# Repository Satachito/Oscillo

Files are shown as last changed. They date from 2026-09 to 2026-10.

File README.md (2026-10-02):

# Oscillo

Oscilloscope projects: one instrument — oscilloscope, spectrum analyser, logic
analyser and meter — on a Raspberry Pi Pico 2 (PiLyzer) or an Arduino R4
(ArLyzer), and the applications that drive both.

| Project | Hardware | Applications |
| --- | --- | --- |
| [Pico2](Pico2/) | Raspberry Pi Pico 2, bare or behind a front end — the [PiLyzer AFE](Pico2/hardware/pilyzer-afe/), a one-op-amp [mini AFE](Pico2/hardware/mini-afe/), or a picoLABO [PL2407AFE](Pico2/hardware/pl2407afe/) | [macOS](Pico2/README.md) · [WebUSB](Pico2/Web/) |
| [ArLyzer](ArLyzer/) | Arduino Nano R4, UNO R4 Minima or UNO R4 WiFi — the same protocol as the Pico 2, up to eight analogue inputs and logic on D2–D9; the UNO R4 WiFi also over Wi-Fi | the same [macOS](Pico2/README.md) · [Web](Pico2/Web/) applications |
| [PCBScope](PCBScope/) | PCBScope / DPScope SE | Native macOS HID application restored from the original project |

**[Open PiLyzer Web](https://satachito.github.io/Oscillo/)** ·
**[Download macOS releases](https://github.com/Satachito/Oscillo/releases)** ·
**[Watch the introduction](https://youtu.be/e5NLnyxRusI)** (6 min, Japanese with English subtitles)

The build log, in English with Japanese subtitles: [PiLyzer #1](https://youtu.be/wvEdqJw_1fM) ·
[PiLyzer #2](https://youtu.be/XWv_rssCQdA) · [ArLyzer on three Arduino R4 boards](https://youtu.be/QQOrhekh34A)

PiLyzer's firmware, KiCad schematics, documentation and native app now live
under `Pico2/`; ArLyzer's sketch and the UNO R4 WiFi's Wi-Fi bridge under
`ArLyzer/`. The Git repository remains at this level. Each native app is
an independent Swift package; run its build commands from its own directory.

```sh
(cd Pico2 && ./Scripts/make-app.sh)
(cd PCBScope && ./Scripts/make-app.sh)
```

PiLyzer Web talks directly to the instrument in Chrome or Edge on a desktop
computer — macOS, Windows and Linux alike, with nothing to install on any of
them: WebUSB for a Pico 2 (firmware 1.6 and later), Web Serial for an ArLyzer.
A Pico 2 W or an UNO R4 WiFi serves it itself over Wi-Fi, at
`http://pilyzer.local` or `http://arlyzer.local`, so a phone or a tablet needs
no USB at all. Demo mode also works without an instrument.
Captured samples remain in the browser; CSV export saves them locally.
From 3.3.6, the copy on GitHub Pages counts page views, and which way an
instrument was connected (USB, serial or the demo), with Google Analytics. The
copy a board serves, and one run locally, load nothing of the kind, and no
samples, readings or device details are sent.

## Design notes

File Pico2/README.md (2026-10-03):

# PiLyzer

A three-channel oscilloscope, spectrum analyser and eight-channel logic analyser
built on a Raspberry Pi Pico 2, with a native macOS application to drive it.

The RP2350 appears as a vendor-specific USB device, so the application claims it
directly through IOKit: no driver, no kext, no permission dialog, no Python.

The macOS application and the browser application in [Web/](Web/) are the same
instrument seen through two windows, and are drawn to match: one palette, one
layout, one set of readings. The colours come from the custom properties at the
top of `Web/style.css`, light and dark alike, and both applications follow the
system appearance.

Only the paper around the instrument changes with it. The screen does not: an
oscilloscope's face is dark on a bench under any lighting, the trace colours are
chosen against that dark, and a screen that inverted with the system would give
every reading a different colour from the one you learned.

## Downloads and Web app

[Download PiLyzer for macOS](https://github.com/Satachito/Oscillo/releases/latest)
(Apple Silicon + Intel, macOS 13+) or
[open PiLyzer Web](https://satachito.github.io/Oscillo/).
The WebUSB app lives in [Web/](Web/) and needs Chrome or Edge for USB — on a
computer, or on Android through USB On-The-Go.
The same release carries the firmware as UF2 files — for a Pico 2, a Pico 2 W
and a Pico 2 on the PL2407AFE; see
[firmware/pilyzer](firmware/pilyzer/README.md#without-building).
From 3.3.6, PiLyzer Web on GitHub Pages counts page views and which way an
instrument was connected; the copy a Pico 2 W serves does not
([Web/README.md](Web/README.md)).

The macOS download is ad-hoc signed, not Apple-notarized. Unzip it and move
PiLyzer.app to Applications. macOS may require approving its first launch in
System Settings → Privacy & Security → Open Anyway.

The same firmware and both applications serve a bare Pico 2, [the rev A front
end](hardware/pilyzer-afe) — three channels, two switched ranges, and a
one-range build for a bench that wants no switch — and a picoLABO
[PL2407AFE](hardware/pl2407afe). None of them needs its own release of either
application: the board describes its own front end from firmware 1.7.

Both applications also drive an Arduino Nano R4, UNO R4 Minima or UNO R4 WiFi
running [ArLyzer](../ArLyzer/), a sketch that speaks this same protocol: up to
eight analogue inputs at 0–5 V and a logic analyser on D2–D9, slower than the
Pico 2 but with more inputs. It connects over USB serial — **Serial** in PiLyzer
Web, the instrument list in the macOS application — and the UNO R4 WiFi also
serves PiLyzer Web itself at `http://arlyzer.local`.

All commands below run from the `Pico2` directory.

## What it is

| | |
| --- | --- |
| Analogue | 3 channels, 12 bits, 40 kHz; 495 / 247 / 165 kSa/s per channel with 1 / 2 / 3 enabled |
| Vertical | ±25 V and ±5 V, switched from the application |
| Record | up to 16 384 points a channel, with pre-trigger |
| Spectrum | windowed FFT of every enabled channel, with averaging, THD, THD+N, SNR, SINAD and ENOB for each |
| Logic | 8 channels, up to 150 MSa/s, 65 536 points, UART / SPI / I²C decoding |
| Trigger | edge, with hysteresis, on any analogue channel or any logic input |

There is a built-in signal generator, so the whole application works with
nothing plugged in:

```bash
swift run PiLyzer --demo
```

`--mode scope|spectrum|logic|meter` opens on one of the four screens, and
`--autostart` connects to the remembered instrument and starts sweeping.

Three flags answer without opening a window, which is what to reach for when an
instrument does not appear in the list:

```bash
swift run PiLyzer --list       # what is on the USB bus, and why it is not an instrument
swift run PiLyzer --selftest   # walk the whole command set against a real board
swift run PiLyzer --timing     # measure the time axis against the calibration output
swift run PiLyzer --testout 1000   # drive that output, or "off"
swift run PiLyzer --signals 440    # sine and the three noises on the board's own pins, or "off"
swift run PiLyzer --bootsel    # restart it in its bootloader to load new firmware
```

## Requirements

* macOS 13 or later
* Xcode 16 or later (Swift 6 toolchain) to build the application
* A Raspberry Pi Pico 2 running the firmware in `firmware/pilyzer`
* Optionally the analogue front end in `hardware/pilyzer-afe`, which is what
  makes anything outside 0–3.3 V safe to measure

## Building and running

```bash
./Scripts/make-app.sh
```

Set `UNIVERSAL=1` to build for both Apple Silicon and Intel. The script
puts a double-clickable, ad-hoc signed `build/PiLyzer.app` together. To run from
the package instead, `swift run PiLyzer`. Tests:

```bash
swift test
```

The whole acquisition path is exercised against the built-in generator, so the
test suite needs no hardware.

The firmware has its own build; see [firmware/pilyzer/README.md](firmware/pilyzer/README.md).

## Using it

1. Pick the instrument (or **Demo signal**) in the toolbar and press
   **Connect** (⌘K). The list follows the hardware as it is plugged and
   unplugged. The application checks the firmware's identity, so nothing else
   on the bus can be mistaken for an instrument.
2. Press **Run** (⌘R) for continuous sweeps, or **Single** (⇧⌘S) for one.
3. **Export** (⌘E) writes what is on screen to CSV — samples, spectrum, logic
   transitions or decoded protocol, whichever screen is showing.

| Screen | |
| --- | --- |
| **Scope** | voltage against time, or X/Y; Vpp, mean, RMS, AC RMS, frequency, duty, rise time |
| **Spectrum** | every enabled channel on one axis, with peak markers and the distortion figures for each |
| **Logic** | eight traces, per-channel rate and duty, protocol decoding |
| **Meter / logger** | all inputs as numbers, and a log at 50 ms to 5 minutes a point — each point the lowest, mean and highest reading of its interval |

### The instrument tells the application what it can do

Nothing about the hardware is compiled into the application. On connecting it
asks the instrument for its capabilities — how many channels, how fast, how
deep, which ranges — and builds the sweep speeds, record lengths and range
menus from the answer. When a sweep is set up, the instrument replies with the
sample interval it will *actually* use, and that is what the time axis is
labelled with.

This is the reason the time axis can be trusted: it is a hardware register
divided down, not a number the application hoped for.

It is also why the same applications drive [ArLyzer](../ArLyzer/) on an
Arduino R4 with no code of its own beyond naming the pins: the board answers
the same questions with its own figures.

### Fast sweeps show fewer points, not invented ones

The converter runs at 165 kSa/s a channel with all three on. A sweep faster than the record length
can be filled at that rate keeps the converter flat out and **shortens the
record** instead of interpolating: at 50 µs/div you get 125 real samples across
the screen rather than 2 000 imaginary ones. The panel always shows the rate and
the point count it settled on.

The other direction is handled by averaging rather than skipping. Every sample
on a slow sweep is the mean of all the conversions underneath it, which is both
the anti-alias filter and where the extra bits below the converter's twelve come
from.

### Triggering a noisy or stepped waveform

**Trigger LPF** in the Scope panel filters only the signal used to find the
trigger. The displayed/exported waveform keeps its original steps and noise.
It defaults to Off. An on/off switch retains the last cutoff, and a logarithmic
slider covers 100 Hz to 100 kHz. The **1 kHz** shortcut enables that cutoff.
For a roughly 194 Hz waveform, 1 kHz is a starting point;
compare Off, 500 Hz, 1 kHz and 2 kHz against the actual signal. Keep the level
near the middle of the waveform, and use Normal mode to distinguish a real
trigger from an automatic sweep.

This setting requires firmware 1.2 or later. The trigger marker follows the
filtered crossing, so the raw trace can cross the level earlier. The filter
uses the actual sample interval, and is reset and allowed to settle at each arm.

### Calibration

Every reading is a straight line from a converter code to a voltage, and the
resistors that set it are ordinary 1% parts. Two points fix them:

1. **Zero.** Ground all inputs, then **Calibrate Zero** (⌘-menu, or the button
   on the channel). Whatever is read becomes zero for the range that channel is
   on.
2. **Gain.** Apply a known voltage and tell the application what it is.

Calibration is stored per channel *and per range*, because the two ranges go
through different amplifier gains.

The front end's frequency compensation is a physical adjustment, not a software
one: the firmware puts a square wave on GPIO22 for it, and
[the front end's documentation](hardware/pilyzer-afe/README.md) explains what to
turn.

## How it is put together

| Target | |
| --- | --- |
| `Sources/CPiLyzerUSB` | IOKit's USB interfaces, wrapped so Swift sees a handle |
| `Sources/PiLyzerCore` | protocol, transport, instrument, engine, FFT, decoders |
| `Sources/PiLyzerApp` | SwiftUI front panel and the four screens |
| `firmware/pilyzer` | RP2350 firmware |
| `hardware/pilyzer-afe` | analogue front end: KiCad schematic, footprints, values, BOM |
| `docs/protocol.md` | the contract between the firmware and the application |

`PiLyzerCore` has no interface dependencies. The real instrument and the demo
generator both implement `Instrument`, so every path from the front panel down
to the samples is covered by the tests.

Device traffic runs on one background queue, and no acquisition ever blocks the
interface.

Run one program against an instrument at a time. The application asks for
exclusive access and refuses to take it away from another process, because two
clients on one bulk endpoint would read each other's answers.

## Limits worth knowing before you trust a reading

* **Bandwidth is 40 kHz**, set by a two-pole Sallen-Key on each channel rather
  than by the converter. The corner is sized for the three-channel case, where
  Nyquist is 82 kHz, so one- and two-channel modes are limited by the filter
  and not by the sample rate. Two poles reduce what folds back; they do not
  abolish it. This is an audio and low-frequency instrument.
* **The fastest sweep is 20 µs/div with one channel, 50 µs/div with two or
  three**, where a division holds five samples. There is no equivalent-time
  sampling yet.
* **Nothing is isolated.** Everything shares the Mac's USB ground. Not for mains
  primary circuits, and not for anything floating at a dangerous potential.
* **The logic inputs are 3.3 V only.** There is no buffer and no level shifter.
* **The analogue and logic sides trigger independently**, so their records
  cannot be lined up against each other.
* A channel that reaches the ends of the converter has its legend label shown
  inverted: the trace is a flattened copy of the real signal and no
  calibration recovers it.

## Where this came from

This started as a rewrite of a macOS application for the DPScope SE, a PIC-based
USB HID instrument. When the hardware became a Pico 2 the old command set came
along with it for a while, and it fitted badly: registers of a microcontroller
that was no longer there, an eight-bit record, 211 samples, and an equivalent
time mode that existed only because the PIC could not sample faster than 30 µs.

None of it survives. The protocol, the firmware, the front end and the
application were designed again around what an RP2350 is actually good at:
hardware-paced conversion into DMA, a processor fast enough to find triggers in
the data, PIO fast enough to watch a pin at 150 MHz, and a USB link fast enough
that records do not have to be small.

## License

MIT. See [LICENSE](LICENSE).

Firmware 1.5 adds CH3 on GPIO28; the test output is GPIO22 (TP6).
Firmware 1.6 adds the WinUSB and WebUSB descriptors that let the browser
application open the instrument on Windows without a hand-installed driver, and
firmware 1.8 is the first in which Windows actually binds to them.
Logic is on GPIO6–13, the range controls are GPIO2/3/4 (firmware 1.13; before
that GPIO8–15 and GPIO4/5/6) and the signal generator has GPIO16–19 — the same four on every board, wherever it is plugged
in. The application uses
the channel count reported by the device, so older two-channel firmware remains
usable. Channel Enabled checkboxes control acquisition as well as display:
1 / 2 / 3 enabled channels allow up to 495 / 247 / 165 kSa/s per channel.
Slower timebases still use averaging/decimation; the actual rate and the current
channel-count limit appear in the Horizontal section.

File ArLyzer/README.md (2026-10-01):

# ArLyzer

PiLyzer's oscilloscope, spectrum analyser, logic analyser and meter on an
Arduino Nano R4, UNO R4 Minima or UNO R4 WiFi. The sketch speaks the same wire
protocol as the Pico 2 ([`Pico2/docs/protocol.md`](../Pico2/docs/protocol.md)),
so [PiLyzer Web](https://satachito.github.io/Oscillo/) and the macOS
application drive it unchanged: the board says what it can do, and the
applications draw from that.

| | Nano R4 | UNO R4 Minima | UNO R4 WiFi |
| --- | --- | --- | --- |
| Analogue | 8 ch, A0–A7 | 8 ch, A0–A5, D4, D5 | 7 ch, A0–A5, D10 |
| Fastest, per channel | 88 kSa/s with 1 input, 47 with 8 | the same | 88 kSa/s with 1 input, 50 with 7 |
| Record | 1,024 points a channel | the same | the same |
| Logic | D2–D9, up to 167 kSa/s, 16,384 points | the same | the same, 14,336 points |
| Connection | USB serial | USB serial | USB serial, and Wi-Fi with [the bridge](bridge/) |

The inputs are 0–5 V: the converter measures against the board's own 5 V
rail, which the firmware reads against the chip's internal reference, so the
readings hold when the USB supply is not quite 5 V. The logic inputs are 5 V
logic — a 3.3 V signal may not read high, so put a level shifter in front of
3.3 V circuits.

## Load it

Open [`arlyzer/`](arlyzer/) in the Arduino IDE with the Arduino UNO R4 Boards
package installed, pick the board and upload. Or with arduino-cli:

```sh
arduino-cli compile --fqbn arduino:renesas_uno:nanor4 arlyzer        # or :minima, :unor4wifi
arduino-cli upload  --fqbn arduino:renesas_uno:nanor4 -p <port> arlyzer
```

The [release](https://github.com/Satachito/Oscillo/releases/latest) carries a
build for each board — `ArLyzer-NanoR4.bin`, `ArLyzer-Minima.bin` and
`ArLyzer-R4WiFi.bin` — to load without building:

```sh
arduino-cli upload --fqbn arduino:renesas_uno:nanor4 -p <port> --input-file ArLyzer-NanoR4.bin   # :minima, :unor4wifi
```

## Use it

In PiLyzer Web (Chrome or Edge), press **Serial** and pick the board's port;
in the macOS application, pick it from the instrument list. Plug the USB in
before any signal: a signal on an unpowered board can power it through the
input pin and stop its USB from starting.

The UNO R4 WiFi can also serve PiLyzer Web itself, at `http://arlyzer.local`,
once its ESP32-S3 runs ArLyzer's bridge — see [`bridge/`](bridge/). The
network is then set from the application's Wi-Fi section, over USB.

## In this directory

| | |
| --- | --- |
| [`arlyzer/`](arlyzer/) | the sketch |
| [`bridge/`](bridge/) | the UNO R4 WiFi's ESP32-S3 firmware: Wi-Fi, `arlyzer.local` and the browser application |
| [`host/`](host/) | a simulated ArLyzer behind a pseudo-terminal, to drive the applications without a board |
| [`tests/`](tests/) | host tests for the record, the logic analyser and the network hand-over |
| [`tools/probe.py`](tools/probe.py) | asks a board who it is and reads its inputs, from the command line |

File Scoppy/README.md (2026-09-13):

# PiLyzer for PL2407AFE

購入したpicoLABO **PL2407AFE + Raspberry Pi Pico 2** 用のPiLyzer構成です。
ScoppyのAndroidアプリやファームウェアのコピーではありません。基板のAFEを利用し、PiLyzerのmacOS／Webアプリで測定します。

## 構成

- `firmware/board_config.h`: PL2407AFE専用GPIO・2ch・3レンジ換算値（board ID 3）。
- `firmware/build.sh`: 共通PiLyzerファームウェアをこの基板用にビルド。
- `Web/`: `../Pico2/Web`へのリンク。同じWebUSBアプリを使用。
- macOS: `../Pico2`のアプリを使用。入力レンジ記述子に対応した最新版が必要です。`cd ../Pico2 && ./Scripts/make-app.sh`でビルド。

アプリは接続したファームウェアから2ch・3レンジを取得します。Webのテスト出力ピン表示はboard IDで選択します。既存Pico2用ファームウェアのビルド設定は変わりません。

## ビルドと書き込み

```sh
./Scoppy/firmware/build.sh
```

出力: `Scoppy/firmware/build/PiLyzer-PL2407AFE-Pico2.uf2`

Pico 2をBOOTSELで接続し、このUF2をコピーします。元のScoppyファームウェアは置き換わります。Scoppy Androidアプリへ戻す場合はScoppy用UF2を書き戻します。
このビルドはRP2350のPico 2用です。初代Pico/RP2040用ではありません。

## 配線・制御

| 機能 | GPIO |
|---|---|
| CH1 / CH2 | 26 / 27 |
| CH1レンジ制御 | 2, 3 |
| CH2レンジ制御 | 4, 5 |
| Logic D0–D7 | 6–13 |
| SG OUT | 22（基板上1kΩ経由） |
| 信号生成器 | 16 サイン, 17 ホワイト, 18 ピンク, 19 ブラウン |

空きGPIOは 0, 1, 14, 15, 20, 21, 28 です。28だけがADC（ADC2）に繋がっています。
23/24/29はPico 2自身が使い、Pico 2 Wでは25も無線モジュール側に行きます。

信号生成器は全ボード共通でGPIO16–19です。PWMスライスはSG OUT（22）と競合
しません。各ピンはPWMキャリアなので、電圧として
使うにはRC（1kΩ + 100nF）が要ります。**起動時に16–19はLow出力として駆動されます**
ので、基板側がこれらのピンに何か繋いでいないかメーカー回路図で確認してください。

CH3のAFEはありません。AC/DCは基板上スイッチで操作します。
各CHの制御ピンをA/Bとすると、±30Vは00、±6Vは01、±1.5Vは10です。
レンジ切替時には一旦00に戻し、両方のバイパスを同時に有効にしません。

## 電圧換算と検証状況

[メーカー回路図・説明](https://picolabo.org/pl2407afe/)のrev.1cを基準にしています。
rev.1dはメーカー説明上仕様変更なしですが、届いた基板のリビジョンと実測は未確認です。

公称抵抗値からのDC計算（アナログスイッチのオン抵抗・部品誤差は未補正）:

- 初段反転増幅器の利得は−0.1。
- 後段の基準電圧は `3.3 × 1 / 25 = 0.132 V`。
- レンジ別の直列抵抗Rsは24230 / 4230 / 330 Ω。
- `gain = 1.2 / (1 + Rs/1000 + Rs/10000)`。
- `offset = 13×0.132 − 12×(0.132/10000)/(1/Rs + 1/1000 + 1/10000)`。
- `Vinput = (Vadc − offset) / gain`。

ADC電源基準とAFE電源の差、抵抗誤差、スイッチ抵抗があるため、到着後に各CH・各レンジで0Vと既知電圧を確認し校正します。最初はDC結合・±30VレンジでGND、続いて既知の小さい信号を確認してください。
AFEの帯域はADCサンプリング速度とは別です。このファームウェアはADCをオーバークロックせず、1ch約495kSa/s、2ch約247kSa/sです。

USB実機での測定・レンジ切替・校正は基板到着後に実施します。

## 自動チェック

`./Scoppy/tests/run.sh`でGPIO・各レンジのADC範囲・2ch取得とCH3拒否を検証します。共通ファームウェアの回帰テストは`./Pico2/firmware/pilyzer/tests/run.sh`です。

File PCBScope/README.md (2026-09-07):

# PCBScope / DPScope SE for macOS

Restored from this repository's `0f8ba4d` revision, before the Pico 2 PiLyzer
rewrite. This is the native HID application for PCBScope / DPScope SE hardware;
it is independent of the Pico 2 vendor-bulk USB instrument in `../Pico2`.
The Swift targets and application bundle keep their original DPScope names.

A native macOS application for the [DPScope SE](https://dpscope.freevar.com/overview_se.html)
USB oscilloscope, written in Swift and SwiftUI.

The DPScope SE only ever shipped with Windows software. It is a PIC18F14K50
that enumerates as a vendor-defined USB HID device, so this app talks to it
directly — no drivers, no serial port, no Python.

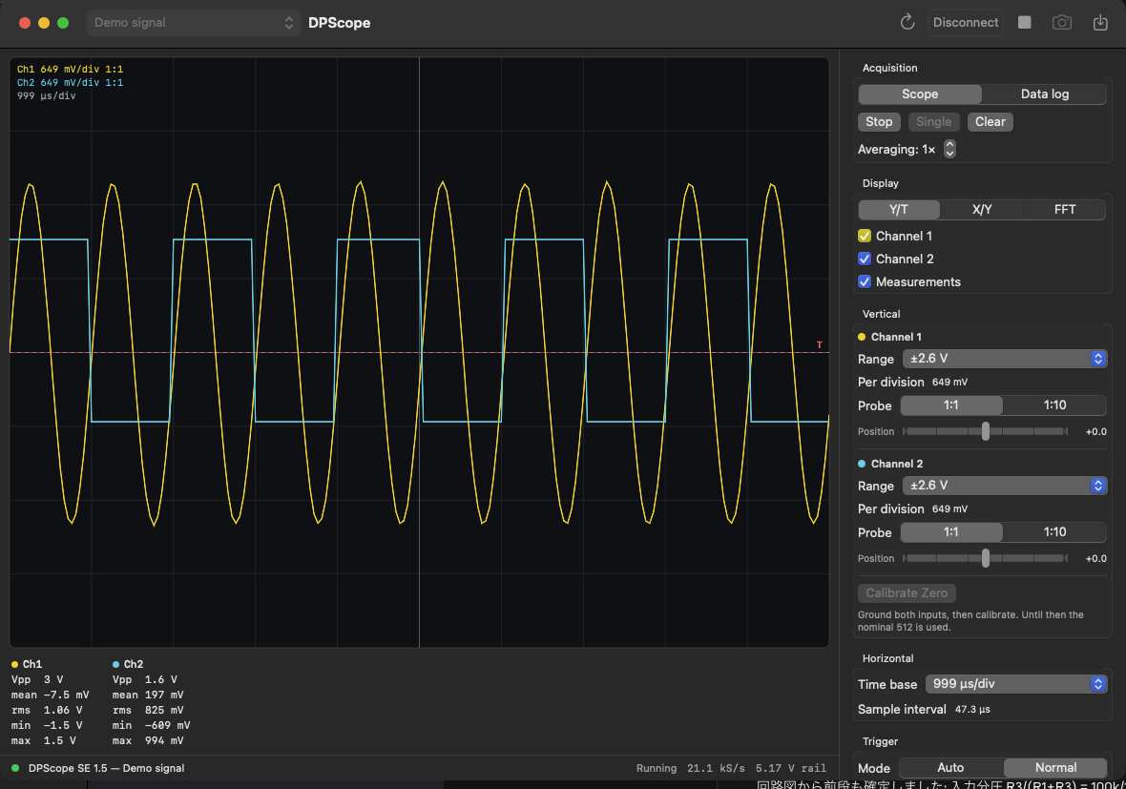
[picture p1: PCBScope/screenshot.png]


*Above: the app running against its built-in signal generator, so the window
looks the same with no hardware attached.*

## Requirements

* macOS 13 or later
* Xcode 16 or later (Swift 6 toolchain) to build
* A DPScope SE. No driver or permission is needed — the scope is a
  vendor-usage HID device and macOS hands it over on request.

## Building and running

Build a double-clickable, ad-hoc signed application bundle:

```bash
./Scripts/make-app.sh
```

It lands in `build/DPScope.app`. To run straight from the package instead:

```bash
swift run DPScope
```

There is a built-in signal generator, so the app is fully usable with no
hardware attached — pick **Demo signal** in the toolbar, or launch with:

```bash
swift run DPScope --demo
```

`--autostart` connects to the remembered instrument and starts sweeping.

Tests:

```bash
swift test
```

Three of them drive a real scope and are skipped automatically when none is
plugged in.

## Using it

1. Pick the scope (or **Demo signal**) in the toolbar and press **Connect**
   (⌘K). The app checks the firmware identity, so nothing else on the USB bus
   can be mistaken for a scope. The list follows the hardware as it is plugged
   and unplugged, and switching the picker while connected moves to the other
   instrument. **Demo signal** is the built-in generator — a 1 kHz sine on Ch1
   and a 500 Hz square on Ch2 — not anything on your probes.
2. Press **Run** (⌘R) for continuous sweeps, or **Single** (⇧⌘S) for one.
3. **Export** (⌘E) writes the trace on screen to CSV.

| Section | Controls |
| --- | --- |
| Acquisition | Scope / data-log mode, run, single, clear, 1–100× averaging |
| Display | Y/T, X/Y and FFT views, channel and readout visibility |
| Vertical | Six ranges from ±26 V to ±0.65 V per channel, 1:1 or 1:10 probe, screen position, zero calibration |
| Horizontal | 10 µs/div – 1 s/div, with equivalent-time sampling above the converter's real-time limit |
| Trigger | Auto or normal, Ch1 or the external trigger pin, rising or falling edge, level |

**Auto** still triggers whenever it can — that is what holds a repetitive signal
still on screen — and sweeps free only when nothing crosses the threshold within
80 ms. **Normal** waits indefinitely and reports when no trigger arrives. The
fastest sweeps use equivalent-time sampling, which builds one record from many
trigger events, so those always trigger whatever the mode says.

A channel whose samples reach the converter's limits is marked **CLIP**: the
trace on screen is a flattened copy of the real signal, and no software
calibration can recover it. On the ×10 ranges this usually means the board's
offset trimmer for that channel needs adjusting.

Readouts under the screen show Vpp, mean, RMS, min and max per channel, and
the front panel comes back the way you left it next launch.

### Calibrate the zero point

Every reading is referenced to the converter code that means 0 V. The board's
offset trimmers set that point, and the ×10 amplifier multiplies whatever error
they leave, so the finer ranges are only as good as this calibration:

1. Ground both inputs.
2. Stop the sweep and press **Calibrate Zero** (also in the Scope menu).

The app measures both amplifier paths on both channels and stores the four
codes. Until then it uses the nominal 512 from the vendor's documentation.

The supply rail is measured automatically at connect through the PIC's 4.096 V
reference, and every volt on screen is scaled by it; **Measure Supply Rail**
repeats that measurement.

## How it is put together

| Target | Contents |
| --- | --- |
| `Sources/DPScopeCore` | HID transport, the SE command set, the simulated scope, unit conversion, FFT, and the acquisition engine |
| `Sources/DPScopeApp` | SwiftUI front panel, scope display, CSV export |
| `Tests/DPScopeCoreTests` | Command encoding, scaling, spectrum, engine tests against the simulator, and hardware tests |

`DPScopeCore` has no UI dependencies, and the real instrument and the simulator
both implement `ScopeDevice`, so the whole acquisition path is exercised by the
test suite without hardware.

Device traffic runs on one background queue and HID input reports are collected
on a private run loop thread, so neither blocks the UI.

Run only one program against a scope at a time. The app asks to seize the
device, but macOS lets another process seize it away, and two clients then
receive each other's replies. Every acknowledged command checks that the scope
echoed the right opcode, so a collision surfaces as a protocol error rather than
as plausible-looking data.

## The instrument's interface

Most of this comes from the vendor's
[DPScope SE Programming Interface Description V1.0.0](https://dpscope.freevar.com/files/DPScope_SE_Interface_Description.pdf)
and the [V1.1 schematic](https://dpscope.freevar.com/files/DPScope_SE_V1_1_schematic.pdf).
The document leaves `CMD_READBACK` blank, and the schematic does not spell out
the channel map, so those were measured on hardware.

* **Connection.** VID `0x04D8`, PID `0xF891`, 64-byte reports, one exchange per
  command. Byte 0 of a command is the opcode; the answer usually starts with the
  same opcode as an acknowledge, though `CMD_REVISION`, `CMD_DONE`,
  `CMD_READADC`, `CMD_READ_LA` and `CMD_READBACK` answer with data only.
* **`CMD_READBACK` (8)** takes a block index and returns 64 bytes: 32 sample
  pairs, channel 1 and channel 2 interleaved, with no acknowledge byte.
* **The record is 211 sample pairs** — six full blocks plus 19 pairs in the
  seventh, after which the buffer holds stale bytes. Timing the acquisition
  agrees: a linear fit over four prescaler/preload combinations gives 423.06
  conversions per record (2 × 211.5) with 4 ms of command overhead.
* **Sample interval** is `2 × (65536 − preload) × prescaler ÷ 12 MHz` **plus a
  fixed 9.8 µs**. Timer0 paces individual conversions and the scope alternates
  channels, so a sample pair costs two timer periods — but the converter's own
  acquisition and conversion time is not covered by the timer, and it adds a
  constant on top. Calibrated by feeding known 220 Hz and 311 Hz square waves
  into both inputs and measuring them back: over timer periods from 20 µs to
  2 ms every sweep ran long by the same 9.80 µs (sd 0.42 µs, n = 35), with no
  dependence on the timer period. With the constant applied, 28 measurements
  spanning both channels and the whole range read back within 0.12% of the true
  frequency on average (worst 0.62%); without it the time axis is wrong by a
  third at the fastest sweeps and still 5% at 200 µs. The constant should track
  ADCON2, so changing the converter timing means re-measuring it.
* **Digital gain** is `sample = (raw10 − 2 × subtract) >> shift`. The documented
  `(shift, subtract)` pairs `(2, 0)`, `(1, 128)` and `(0, 192)` all keep 0 V at
  code 128 under this form, and only under this form — `(0, 192)` measured 187
  where the raw reading was 571.
* **ADC channels.** AN5 = Ch1 ×1, AN6 = Ch1 ×10, AN7 = external trigger,
  AN8 = Ch2 ×1, AN9 = Ch2 ×10, AN15 = the 4.096 V reference. Confirmed by
  reading every channel: the ×10 readings track the ×1 readings amplified about
  ten-fold, and the comparator inputs C12IN1-/2-/3- line up with the trigger
  channel numbers the ARM command takes.
* **Front end.** The input divider is R3 / (R1 + R3) = 100 kΩ / 1009 kΩ, and the
  second stage is 1 + R7 / (R4 ∥ R6) = 1 + 4.53 kΩ / 500 Ω = 10.06. So the ×1
  path spans about ±26 V and the ×10 path — almost exactly 1:1 at the converter
  — about ±2.6 V.

Not implemented: `CMD_ARM_LA`, the logic analyzer's own acquisition mode, which
is the other section the vendor's document leaves blank. The four logic inputs
can still be read one state at a time with `CMD_READ_LA`.

## A test signal

`tools/pico2-signal-generator/sine440.py` is a MicroPython module for a
Raspberry Pi Pico 2 that puts a sine on GPIO 26, for checking the scope against
a known signal. The RP2350 has no DAC, so it modulates a PWM carrier with a sine
table fed by DMA and paced by the PWM's own wrap signal — the timing is entirely
hardware, with no interrupt or Python loop in the path. Add an RC low-pass
(1 kΩ + 100 nF) on the pin to turn the 113 kHz carrier back into a sine.

```python
import sine440
gen = sine440.start()        # 439.893 Hz — as close to 440 as 150 MHz divides
gen = sine440.start(1000)
gen.stop()
```

`tools/pico2-chord/` is the C++ version for the same board: eight square waves —
a chord over two octaves — on GPIO 1, 3, 5, 7, 9, 11, 13, 15, accurate to
within 7 ppm and needing no filter at all. Change `kChord` and `kSemitones` at
the top of `chord.cpp` to play something else. It is what the timing constant
above was measured with.

Either output swings the full 0–3.3 V rail, so measure it on the ±6.5 V range or
coarser; ±2.6 V would clip the peaks.

## Where this came from

It started as a rewrite of Pepijn de Vos's
[DPScope](https://github.com/pepijndevos/DPScope), a Python 2 / Tkinter /
matplotlib program for the *original* DPScope. That is a different instrument:
an FTDI serial port at 500 kbaud with an unrelated command set. None of its code
survives here — the SE speaks USB HID and needed a driver of its own — but it is
where this project began, and it is worth a look if you have the older scope.

## License

MIT. See [LICENSE](LICENSE).

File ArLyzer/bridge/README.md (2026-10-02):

# ArLyzer over Wi-Fi on an UNO R4 WiFi

The UNO R4 WiFi's USB port and its radio both belong to an ESP32-S3, which
runs Arduino's bridge firmware: a USB-to-UART bridge to the RA4M1, the
programmer that uploads sketches, and an AT-command server that the WiFiS3
library drives over a second UART. This directory builds that same firmware
with the AT server swapped for ArLyzer's own network side
(`arlyzer_net.cpp`), the way a Pico 2 W serves PiLyzer:

- it joins the network the app gives it and answers to
  **`http://arlyzer.local`** over mDNS;
- it hands out the browser application from its own flash, gzipped;
- it passes each `POST /rpc` to the RA4M1 over the second UART, at 230400
  baud, and sends the reply back — the same frames the USB port carries, so
  the browser application connects to it exactly as it does to a Pico 2 W.

Everything else in the bridge is Arduino's and stays as it was: the USB serial
port, sketch uploads from the Arduino tools, the CMSIS-DAP interface, and the
HID request that restarts the ESP32-S3 into download mode (which is how
`flash.sh` writes it, and how Arduino's updater puts its own firmware back).

The RA4M1 runs the ordinary ArLyzer sketch (`../arlyzer`), which on a WiFi
answers on its USB port and on that second UART at once. With Arduino's
firmware on the ESP32-S3 nothing arrives on the second UART, and the sketch
works over USB alone.

## Build

```sh
./build.sh
```

No network goes into the build: the app sets it (below), so the same build
serves every board and can be handed out. `ARLYZER_WIFI_SSID` and
`ARLYZER_WIFI_PASSWORD` build one in for a board that has never been told
one — such a build carries the password, so it is not for handing out.
`ARLYZER_HOSTNAME` changes the default name from `arlyzer`.
The first run fetches Arduino's bridge at the commit `build.sh` names, its
submodules and its ESP32 toolchain into `build/` — about 1 GB — and later runs
reuse them. A built-in network goes into `build/.../arlyzer_config.h`, never
into the repository. The browser application is built from `../../Pico2/Web` and baked
in with the Pico's own `bake-web.py`; `http_request.c`, which reads the
requests, is the Pico's too, with its host tests.

## Flash

```sh
./flash.sh
```

or, with the images from a release unzipped somewhere, `./flash.sh
that/folder` — no build needed, only esptool (`pip install esptool`, which
brings pyserial) and Xcode's command-line tools.

No jumper: it asks the bridge to restart into the ROM's download mode and
writes with the esptool that came with the toolchain. The board comes back in
download mode afterwards — the request is remembered across esptool's reset —
so **unplug its USB and plug it back in** to start the new firmware (signal
wires off the board first, as always). **The first time, it
reads the whole 4 MB flash back into `build/esp32-original.bin` before writing
anything**, so Arduino's firmware can be put back byte for byte:

```sh
esptool --chip esp32s3 --port /dev/cu.usbmodemXXXX write_flash 0 build/esp32-original.bin
```

Arduino's updater
([unor4wifi-updater](https://github.com/arduino/uno-r4-wifi-usb-bridge/tree/main/unor4wifi-updater))
restores its current release just as well.

## Set the network

Connect the board over USB in the Mac or browser application: a Wi-Fi
section appears (ArLyzer firmware 0.7 on the RA4M1, and this bridge on the
ESP32-S3). Type the network, its password and, if you like, another name, and
save. The radio is 2.4 GHz only.

The application talks to the RA4M1, and the RA4M1 hands the network on: the
bridge asks it once a second over the UART between them, takes the network,
keeps it in the ESP32-S3's NVS — which `flash.sh` leaves alone, so it survives
an update — and joins. The password is never read back, and the RA4M1 forgets
it once the bridge has it. `Forget` erases it, and the radio driver's own copy
too. Pico2/docs/protocol.md has the exchange.

## What to expect

A record comes across at the UART's 22 kB/s: about 0.1 s for one input's 1024
samples, 0.65 s for all seven. The page itself comes from the ESP32-S3 at the
radio's own speed.

A join usually takes a few seconds. Once on the network the bridge waits for
an address as long as it takes, as a Pico 2 W does, and tries again only when
getting onto the network fails. **`http://arlyzer.local/wifi-log`** says what
the radio did since it started: each attempt, the DHCP client's state, and how
many frames came in — broadcast ones apart — and how many DHCP messages went
each way. A Buffalo router on the bench sometimes held back everything
broadcast on 2.4 GHz, DHCP replies included, for a minute or more after the
board came back (mostly after `flash.sh`, which drops the board off the
network without a word); the log then shows `in 0` until it lets go.

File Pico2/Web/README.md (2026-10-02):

# PiLyzer Web

**[Open the app](https://satachito.github.io/Oscillo/)**

A static browser application for the Pico 2 PiLyzer instrument. USB packets use
exactly the same [protocol](../docs/protocol.md) as the macOS application. No
server, account, external font or runtime dependency is involved. The copy on
GitHub Pages counts page views with Google Analytics, and which way an
instrument was connected (USB, serial or demo); the copy a Pico 2 W or an
UNO R4 WiFi serves, and one run locally, load nothing of the kind. Samples,
readings and device details are never sent anywhere: they stay in browser
memory until exported locally as CSV.
The [privacy policy](https://satachito.github.io/Oscillo/privacy.html) says
the same for the Mac app, the web app and the firmware.

## Connecting

1. Use Chrome or Edge over HTTPS (or localhost when developing), on a computer
   or on Android. Safari has no WebUSB at all, on any platform, so nothing
   reaches the instrument from an iPhone or iPad.
2. Plug in a Pico 2 running PiLyzer firmware. Disconnect the native app and
   other tabs first: only one application can claim the USB interface.
3. Click **Connect USB** and select **PiLyzer Pico 2** in the browser chooser.
4. Set input range and trigger, then press **Run** or **Single**.

Safari and Firefox can use Demo but do not currently provide WebUSB. A Pico in
BOOTSEL does not appear in the PiLyzer chooser; install the firmware first.

Windows needs **firmware 1.8 or later**, which names WinUSB for itself through
a Microsoft OS 2.0 descriptor. There is nothing to install: plug the instrument
in and the browser can open it. Firmware 1.7 and earlier leave the interface
unbound — 1.5 and earlier carry no such descriptor at all, and 1.6 and 1.7 put
it where Windows does not look — and Windows will not open the interface without
a driver association added by hand. macOS and Linux are unaffected either way.

## Features

- Scope: 1–3 channels according to device capabilities, voltage/probe scales,
  vertical position, mean removal, peak-to-peak/RMS/mean/frequency readouts.
  Remove mean belongs to the scope alone, and the panel greys it out elsewhere:
  the spectrum takes the mean out itself — a DC offset through the window is a
  skirt across the low bins rather than a tall bin at zero — and the meter's
  whole job is the reading the converter made.
- X/Y draws the first two enabled channels on a square grid, so a division is
  the same size on both axes and a Lissajous figure has its real shape. The
  horizontal axis is the first channel, the vertical axis the second.
- Channel checkboxes change the ADC acquisition mask and the rate ceiling.
  Firmware 1.5 and later advertise a 97-cycle minimum: approximately 494.8 / 247.4 /
  164.9 kSa/s per channel with 1 / 2 / 3 enabled. The UI always uses the device's
  advertised timing and actual returned acquisition plan.
- Auto, Normal and Free run; rising/falling edges, pretrigger position,
  hysteresis, trigger-only LPF when supported by firmware.
- Spectrum: Hann-window FFT of every enabled channel on one axis, RMS amplitude
  in dBV, and the peak and bin resolution for each channel. An input and an
  output overlaid read as a gain directly, the difference in dB.
- Logic: D0–D7, rate/record selection, hardware edge trigger, UART 8N1 decode.
- Logger: all ADC inputs, at an interval from 50 ms to 5 minutes, for up to
  20,000 points — two months at the slowest. Each point holds the lowest, mean
  and highest reading of its own interval rather than one instant, so a slow log
  still shows what happened between the points; the chart draws the mean as a
  line with that spread shaded behind it, and the CSV has all three.
- Adjustable calibration square wave, and the instrument's own generator: a
  sine with white, pink and brown noise on the three pins beside it. The panel
  names them: GPIO16–19, the same four on every board. Each of those pins is a
  PWM carrier and wants an RC to be a voltage.
- Per-channel bias and gain. The bias is where a front end holds the input with
  nothing on it: it is **drawn** as a dotted line, with a triangle marking what
  a grounded input actually read, and never taken out of a reading — what the
  screen shows is what reached the converter. The gain is a real correction,
  measured from one known voltage against the bias, and shown as a percentage
  because a correction nobody can see is one nobody can question. Both refuse a
  capture that is moving, and a gain past a tenth is refused outright: 1% parts
  are out by two, so more than that is the wrong reading.
- Light and dark follow the system. Only the paper around the instrument
  changes: the screen stays dark, because that is what an oscilloscope's face
  is under any lighting and the trace colours are chosen against it.
- Local CSV export for scope, spectrum, logic and meter records. A scope file
  is what the screen shows — centred where Remove mean is on — and says in a
  comment which column had its mean taken out, and how much came off.
- The front panel is remembered in this browser between visits, the bias and
  the gain included: they describe the wiring rather than a moment.
- A trigger level is left exactly where it was set, even where nothing will
  cross it, and the panel says so. One that cannot fire on the channel it
  watches starts at that channel's bias when an instrument answers.
- Independent 3-channel demo; no instrument required.

Demo waveforms are generated in the browser and are not measurements. The
native application's software spectrum averaging and SPI/I²C decoders are not
included in this web version. All meter inputs are read regardless of scope
checkboxes. The Pico ADC multiplexes channels rather than sampling simultaneously.

## Development and checks

Requires Node.js 22 or later. There are no npm dependencies.

```sh
npm ci
npm test
npm run dev    # http://localhost:4173
npm run build  # self-contained output in dist/
```

Protocol tests cover sparse channel masks, trigger slots, timing limits,
voltage conversion, bulk stream fragmentation/ZLP, transaction ordering,
malformed replies, FFT amplitude, UART decoding and acquisition cancellation.

The wire format is written twice, once here and once in Swift, so both are
checked against `tests/fixtures/wire-golden.json` — encodings written from
`../docs/protocol.md` rather than recorded from either implementation. A change
on one side that the other does not follow fails `npm test` here and
`swift test` in the native project.

GitHub Actions builds and deploys `dist/` using the repository's Pages workflow.
All asset paths are relative, so the same build works at `/Oscillo/` or locally.

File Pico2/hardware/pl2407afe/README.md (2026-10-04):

# PiLyzer for PL2407AFE

購入したpicoLABO **PL2407AFE + Raspberry Pi Pico 2** 用のPiLyzer構成です。
ScoppyのAndroidアプリやファームウェアのコピーではありません。基板のAFEを利用し、PiLyzerのmacOS／Webアプリで測定します。

## 構成

- `board_config.h`: PL2407AFE専用GPIO・2ch・3レンジ換算値（board ID 3）。
  `../../firmware/pilyzer/board_config.h`がboard ID 3のときにこれを取り込みます。
- `build.sh`: 共通PiLyzerファームウェアをこの基板用にビルド。
- `tests/`: GPIO・レンジ・2ch取得の自動チェック。
- アプリは共通です。Webは[`../../Web`](../../Web)、macOSは`cd ../.. && ./Scripts/make-app.sh`。

アプリは接続したファームウェアから2ch・3レンジを取得します。既存Pico2用ファームウェアのビルド設定は変わりません。

## ビルドと書き込み

```sh
./Pico2/hardware/pl2407afe/build.sh
```

出力: `Pico2/hardware/pl2407afe/build/PiLyzer-PL2407AFE-Pico2.uf2`

ビルドしなくても、[リリース](https://github.com/Satachito/Oscillo/releases/latest)に同じ構成の`PiLyzer-PL2407AFE-Pico2.uf2`があります。

Pico 2をBOOTSELで接続し、このUF2をコピーします。元のScoppyファームウェアは置き換わります。Scoppy Androidアプリへ戻す場合はScoppy用UF2を書き戻します。
このビルドはRP2350のPico 2用です。初代Pico/RP2040用ではありません。

## 配線・制御

| 機能 | GPIO |
|---|---|
| CH1 / CH2 | 26 / 27 |
| CH1レンジ制御 | 2, 3 |
| CH2レンジ制御 | 4, 5 |
| Logic D0–D7 | 6–13 |
| テスト出力（SG OUT） | 22（基板上1kΩ経由） |
| 信号生成器 | 16 サイン, 17 ホワイト, 18 ピンク, 19 ブラウン |

空きGPIOは 0, 1, 14, 15, 20, 21, 28 です。28だけがADC（ADC2）に繋がっています。
23/24/29はPico 2自身が使い、Pico 2 Wでは25も無線モジュール側に行きます。

テスト出力と信号生成器のピンは全ボード共通です。この基板のSG OUTが22にあり、
16–19が空いていたので、他のボードがそれに合わせました。PWMスライスも競合しません。
生成器の各ピンはPWMキャリアなので、電圧として使うにはRC（1kΩ + 10nF）が要ります。
**起動時に16–19はLow出力として駆動されます**ので、基板側がこれらのピンに何か
繋いでいないかメーカー回路図で確認してください。

CH3のAFEはありません。AC/DCは基板上スイッチで操作します。
各CHの制御ピンをA/Bとすると、±30Vは00、±6Vは01、±1.5Vは10です。
レンジ切替時には一旦00に戻し、両方のバイパスを同時に有効にしません。

## 入力保護

**BNCから見た絶対最大入力電圧は ±40 V です（メーカー公称）。レンジ設定によらず
一律です。**

分圧がレンジ切替スイッチより前にあるからです。BNCは直結で 940 kΩ + 120 kΩ を
見ており、レンジ別の直列抵抗（24230 / 4230 / 330 Ω）はその後ろ、減衰済みの信号を
受ける位置にあります。**アプリからレンジを変えても、入力端の耐圧は変わりません。**

ここから導いた数字（公称値からの計算で、実測ではありません）:

| | 値 |
|---|---:|
| BNCが最初に見る抵抗 | 940 kΩ |
| ±40 V を加えたときの入力電流 | 43 µA |
| 分圧比（120 kΩ が対GNDのシャントとして） | 0.113 |
| ±40 V のときの分圧点 | 4.53 V |

43 µA では抵抗は焼けません。±40 V を決めているのは電流ではなく、**分圧点が
能動素子に見せる電圧**の方です。5 V 動作のオペアンプの絶対最大入力
（V+ +0.3 V = 5.3 V）には 47 V 前後で到達する計算で、±40 V という公称値と
整合します。超えたときに起きるのは抵抗が焼けることではなく、オペアンプか
アナログスイッチの入力に食い込むことです。**壊れ方が静かで気づきにくい**ので、
上限は余裕を持って扱ってください。

120 kΩ がシャントなのか基準電圧側なのかは未確認です。どちらであってもBNCが
940 kΩ で受けることは変わりません。

### 使うときの線引き

- **絶対最大定格は常用の上限ではありません。**±30 V レンジに対する余裕は
  1.33 倍しかなく、リレーやモーターの逆起電力、電源投入時のリンギング、車載
  12 V 系のロードダンプ（40〜100 V に達します）を吸収できません。±30 V レンジは
  「30 V を測るため」ではなく「20 V くらいまでを安心して測るため」と考える方が
  安全です。
- **絶縁はありません。**GNDはUSB経由でホストの筐体に繋がっています。
- **商用電源は測れません。**100 V ACはピーク141 V、絶対最大の3.5倍です。
- ×10プローブを使えば入力は1/10になりますが、**プローブ自体の耐圧が足りている
  場合に限ります**。パネルのプローブ倍率も忘れずに合わせてください。

参考までに、自作の[PiLyzer AFE](../pilyzer-afe/README.md)は入力1 MΩで±25 Vレンジ、
連続100 V定格 ── 余裕が4倍あります。設計の狙いが違うので、そのつもりで。

## 電圧換算と検証状況

[メーカー回路図・説明](https://picolabo.org/pl2407afe/)のrev.1cを基準にしています。
届いた基板は**rev.1d**で、電源構成はrev.1cと同じでした。実測値は下の「校正」の項にあります。

公称抵抗値からのDC計算（アナログスイッチのオン抵抗・部品誤差は未補正）:

- 初段反転増幅器の利得は−0.1。
- 後段の基準電圧は `3.3 × 1 / 25 = 0.132 V`。
- レンジ別の直列抵抗Rsは24230 / 4230 / 330 Ω。
- `gain = 1.2 / (1 + Rs/1000 + Rs/10000)`。
- `offset = 13×0.132 − 12×(0.132/10000)/(1/Rs + 1/1000 + 1/10000)`。
- `Vinput = (Vadc − offset) / gain`。

ADC電源基準とAFE電源の差、抵抗誤差、スイッチ抵抗があるため、各CH・各レンジで0Vと既知電圧を確認し校正してください。最初はDC結合・±30VレンジでGND、続いて既知の小さい信号を確認します。
AFEの帯域はADCサンプリング速度とは別です。このファームウェアはADCをオーバークロックせず、1ch約495kSa/s、2ch約247kSa/sです。

上の式は公称抵抗値からの計算です。**実測で置き換えた値が
`board_config.h` に入っています**（下記）。

## 校正（2026-09-22）

乾電池4本の**5.01 V**を入力し、0 Vと合わせた2点で求めました。変換器側の読みは
4回測定して0.5 mV以内に揃っています。テスタが5.01 Vと5.02 Vを行き来したため、
**ゲインには約0.2 %の不確かさ**が残ります。律速はテスタで、こちらの読み取りの
寄与は0.03 %程度です。

| | | 公称 | 実測 |
| --- | --- | --- | --- |
| ±30 V | gain | 0.043395 | CH1 0.043974 / CH2 0.044140 |
| | offset | 1.577207 V | CH1 1.586325 V / CH2 1.582325 V |
| ±6 V | gain | 0.212277 | CH2 0.214483 |
| | offset | 1.597473 V | CH2 1.602975 V |
| ±1.5 V | gain | 0.880411 | CH1 0.882035 / CH2 0.878957 |
| | offset | 1.677649 V | CH1 1.681950 V / CH2 1.684700 V |

レンジ表はチャンネルごとではなく**基板ごとに1本**なので、`board_config.h`には
**CH1とCH2の平均**を入れてあります。両チャンネルの差は0.5 %ほどで、これは
アプリ側のチャンネルごとのゲイン補正が吸収する範囲です。

±1.5 Vだけは5 Vがレンジ外なので、**1.3 Vの電池**で測りました。ただしテスタは
1.30 Vまでしか読めず、真値が1.295〜1.305のどこかだと**±0.38 %**の不確かさに
なります。そこで**校正済みの±6 Vレンジを物差しに使い**、それがこの電池を
1.3078 Vと読んだ値を採用しました。元の5.01 V測定の誤差だけが伝わるので
**±0.2 %**、約2倍の精度です。

この手が使えるのは回路が素直だからです。**±30 Vのゲインは5.01 Vと1.30 Vで
0.03 %一致**しており、直線性は確認済みです。

結果は公称値と**0.010 %差**でした。測定の不確かさ（±0.2 %）の20分の1なので、
区別がつきません。このレンジに限っては名目抵抗値からの計算が当たっていた、
ということです。

なお、これは「ADCの基準電圧が共通の原因では」という見立てを否定します。基準
電圧がずれていれば**全レンジが同じ率でずれる**はずで、±30 Vが+1.5 %、±6 Vが
+1.1 %、±1.5 Vが0 %という散り方にはなりません。レンジごとに効く抵抗の個体差、
と見る方が妥当です。offsetが一様に+5〜9 mV上振れしている件は別で、こちらは
後段の基準0.132 Vを作るR15/R26と、ADC基準の両方が候補として残ります。

## 実機立ち上げ（2026-09-22）

組み立てた基板は**rev.1d**（シルク表記）。Pico 2（シリアル
`9B5C456F3E8EAF87`）にファームウェア1.16、board ID 3で通電しています。

メーカーの公開回路図はrev.1cまでですが、電源構成は同じでした。基板端、取り付け
穴の脇に**GND / VBUS / +3V3 / −3V3**の4つのランドが並んでいます。U3〜U6はPicoの
真下に隠れるので、電源の確認はここで行います。オペアンプもアナログスイッチも
**±3.3 V**で動くので、−3V3が出ていなければ何も正しく動きません。

### 直した不具合

**VBUSがAFEに届いていなかった。** Picoの物理40番ピンのハンダ不良です。VBUSが
ないとU3もU4も動かないので、**+3V3と−3V3が同時に死にます**。このとき基板全体が
GPIOとADCの保護ダイオード経由で逆流した約2.2 Vで浮いており、+3V3ランドも2.23 V
という中途半端な値を示していました。レギュレータの出力なら3.3 Vか0 Vのどちらか
なので、**中途半端な電圧は「電源が来ていない」の兆候**です。オペアンプは
±3.3 Vを失って出力が正側レールに張り付き、ADCは2.22 V / 0.66 Vを読んでいました。

**GPIO2がU2の6番ピン（3S）に届いていなかった。** ソケットのハンダ不良です。CH1の
±1.5 Vレンジだけが効かない、という形で出ました。

### 入力開放での実測（未校正）

| レンジ | CH1 | CH2 | 公称offset |
| --- | --- | --- | --- |
| ±30 V | 1.5864 V | 1.5827 V | 1.5772 V |
| ±6 V | — | 1.6032 V | 1.5975 V |
| ±1.5 V | 1.6830 V | 1.6861 V | 1.6776 V |

CH2は3レンジとも公称値どおりの階段になっています。

### J1のピンソケット

**細い線では接触しません。**回路図上、J1の2・4・6番のGNDは同一ネットで、基板裏の
半田面では導通しています。それでも穴に差した線とは導通しないことがあり、ブレッド
ボード用の単線やデュポンのメス端子では2.54 mmソケットのバネ接点に届きません。
抵抗の足か、オスピンヘッダを差してそこに繋いでください。

## 自動チェック

`./Pico2/hardware/pl2407afe/tests/run.sh`でGPIO・各レンジのADC範囲・2ch取得とCH3拒否を検証します。共通ファームウェアの回帰テストは`./Pico2/firmware/pilyzer/tests/run.sh`です。

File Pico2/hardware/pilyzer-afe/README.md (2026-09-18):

# PiLyzer analogue front end, rev A

Three DC-coupled analogue channels and eight logic inputs for a Raspberry Pi
Pico 2. Design status: **KiCad schematic captured and footprints assigned;
prototype measurements and PCB layout remain.** Open
[`kicad/pilyzer-afe.kicad_pro`](kicad/pilyzer-afe.kicad_pro) in KiCad 10.
The four sheets cover the Pico/power/logic interface, CH1, CH2 and CH3.
See [`kicad/README.md`](kicad/README.md) for checks, sources and capture corrections.

This board is USB-ground referenced and **not isolated**. It must not be used
on mains primary circuits, on anything floating at a dangerous potential, or on
any circuit that is unsafe to connect to the Mac's USB ground.

## What it is for

| | |
| --- | --- |
| Channels | 3, DC coupled, about 1.06 MΩ in |
| Ranges | ±25 V and ±5 V, switched under software control |
| Resolution | 12 bits, extended by averaging on slow sweeps |
| Sample rate | 495 / 247 / 165 kSa/s per channel with 1 / 2 / 3 enabled |
| Analogue bandwidth | 40 kHz, set by a two-pole Sallen-Key on each channel |
| Logic | 8 inputs, 3.3 V only, up to 150 MSa/s |

The sample rate is the honest ceiling of the RP2350's converter, and it is what
decides the rest: there is no point building a megahertz front end in front of
it.

## The anti-alias filter

Each channel ends in a **unity-gain Sallen-Key low pass** before the converter.
It replaced a pair of passive RC sections that were sized when this was a
two-channel board: a third channel divides the converter three ways instead of
two, Nyquist fell from 124 kHz to 82 kHz, and the old passband reached past it —
so a signal between 82 kHz and roughly 250 kHz was neither rejected by the
filter nor resolved by the converter. It folded back and appeared as a lower
frequency that looked perfectly real.

Equal resistors make the arithmetic short:

```text
fc = 1 / (2π · R · √(C1 · C2))       Q = ½ · √(C1 / C2)
R = 2.67 kΩ   C1 = 2.2 nF   C2 = 1 nF
   -> fc = 40.2 kHz, Q = 0.742 (near Butterworth)
```

| | response |
| --- | ---: |
| 20 kHz — the top of the audio band | −0.1 dB |
| 40 kHz — the corner | −2.6 dB |
| 82.5 kHz — Nyquist with three channels | −12.5 dB |
| 124 kHz — Nyquist with two | −19.5 dB |
| 247 kHz — Nyquist with one | −31.6 dB |

`check_transfer.py` prints this table and is the thing to re-run after changing
a value.

Two poles cannot make aliasing go away, and it would be wrong to say it has.
What it does is turn a signal just past Nyquist from something that arrives at
nearly full amplitude into something that arrives at a quarter of it, and
everything an octave further out into a fortieth. The rest of the protection
comes from the firmware, which box-car averages every sample on a slow sweep
and so filters again at whatever rate is actually in use.

**The trade this makes.** The corner is fixed, so it is sized for the
three-channel case, which is the default. One- and two-channel modes are then
limited by the filter rather than by the converter: with a single channel the
converter would reach 247 kHz of Nyquist but the front end still stops at
40 kHz. Raising R to 3.48 kΩ moves the corner to 31 kHz and buys 4.5 dB more
rejection at Nyquist for 0.3 dB more loss at 20 kHz; that is the one value to
change if the balance is wrong.

**Choosing the parts cost nothing extra.** R is a value the board already uses
(R8 sets the fine-range gain), C2 is the 1 nF already in the BOM, and the
amplifier is a second TLV9064 — the same part number as U1. Only the 2.2 nF is
new, so the whole filter adds a single part type to the order.

## The signal path

Two stages per channel. The attenuator is **fixed**, and only the gain after it
changes with the range — which is what lets one frequency compensation serve
both ranges instead of needing a different trimmer for each.

```text
IN -- R1 499k -- R2 499k -- NODE --> U1A (+)
 |__________________________|
       C1 5.6p || TC1

NODE -- R3 125k -- 3V3     NODE -- R4 143k -- GND
NODE -- C4 82p -- GND      NODE -- BAV199 rail clamps -- GND / 3V3

U1A OUT -- R5 2.67k -- SK -- R6 2.67k -- U4A (+)
                       |                |
                    C21 2.2n          C6 1n
                       |                |
                   U4A OUT             VMID

U4A OUT -- U4A (-)            (unity gain)
U4A OUT -- R44 1k -- ADC -- C7 1n -- GND

U1A OUT -- R7 10k -- U1A (-) -- R8 2.67k -- U2A COM
U2A NO -- VMID        U2A NC -- not connected
GPIO2 LOW: COM-NC (gain 1); HIGH: COM-NO (gain 4.745)
```

* **R1 + R2** are the 1 MΩ input, split in two so each 0805 sees half the
  voltage. That is what sets the working voltage, not a number on a datasheet
  for the pair.
* **R3 and R4** bias the divider node so that 0 V at the input lands on mid
  rail. They are deliberately *not* equal: the input resistor pulls the node
  toward ground, and R3 being the smaller leg is what cancels it.
* **C1 and C4** compensate the divider. Without them the ranges roll off at a
  few tens of kHz, differently from each other, and a square wave comes back
  with the wrong shape.
* **The op amp** is a follower when the switch is open, and a ×4.745 amplifier
  referenced to VMID when it is closed. R7 carries no current with R8
  disconnected, so the open position is exactly unity — there is nothing to
  calibrate about it.
* **SW** is the range switch, and it sits at VMID on both sides. Its
  on-resistance therefore never sees a signal swing, so it adds a fixed 0.2%
  gain error that calibration removes rather than distortion that nothing can.
* **R5, R6, C21 and C6 with U4A** are a unity-gain Sallen-Key low pass, the
  anti-alias filter. C6 returns to VMID rather than to ground: VMID is AC
  ground and is buffered, so the filter passes the mid-rail bias through
  untouched and stays ratiometric with the converter's reference.
* **R44 and C7** isolate the filter's output from the converter's sampling
  capacitor and give it a charge reservoir to draw on.

VMID is 3V3 halved by two 10 kΩ resistors and buffered by U1D. C15 (1 µF)
is across the lower divider resistor, before the buffer.

Two quads carry the analogue path. U1 is the gain stages — U1A, U1B, U1C — plus
U1D for VMID; U4 is the three anti-alias filters, U4A, U4B and U4C, leaving U4D
as the only spare amplifier on the board. Tie its input to VMID and close the
loop rather than leaving it floating.

## Why the bias comes from 3V3 and must keep coming from 3V3

The converter's reference on a Pico 2 is the 3V3 rail, filtered. This board's
bias and VMID come from the same rail, so a wobble in it moves the reading and
the reference **by the same fraction** and cancels to first order. That is worth
more than a precision reference would be.

So: do not "improve" this by filtering the front end's supply separately, and do
not fit an external reference on ADC_VREF unless the bias legs and VMID are
moved onto it as well. Splitting them is the one change that would quietly make
every reading worse.

## The numbers

With the nominal values above:

```text
±25 V range (switch open, gain 1)
    Vadc = 1.650515 V + 0.062645 · Vin
    −25 V → 0.0844 V     0 V → 1.6505 V     +25 V → 3.2166 V

±5 V range (switch closed, gain 4.745)
    Vadc = 1.652442 V + 0.297269 · Vin
     −5 V → 0.1661 V     0 V → 1.6524 V      +5 V → 3.1388 V
```

The fine range's amplifier is 4.745 rather than a round 5, and that is the
reason R8 is 2.67 kΩ. At a gain of 5 the nominal range fits, but the 1% corner
of the resistor stack pushes the ends of ±5 V past the converter — the script
prints −0.017 V and 3.310 V — and a range that clips on a bad batch is worse
than one that is 5% short. At 4.745 the worst corner is 0.073 V to 3.220 V,
inside the converter with the tolerances at their least helpful.

The coarse range has no such problem: 1% parts move its ends by ±32 mV against
84 mV of headroom.

Input impedance is 998 kΩ + (125 kΩ ∥ 143 kΩ) = 1.065 MΩ. The node the op amp
looks at is 62.5 kΩ, which is what sets the compensation ratio:

```text
C1 · (R1 + R2) = C_node · (R3 ∥ R4)
C1 = C_node · 66.7 k / 998 k = C_node / 15.0
```

With C4 at 82 pF plus roughly 18 pF of stray and amplifier capacitance, C1
comes out at 6.7 pF, so 6.8 pF is the part and TC1 beside it is the adjustment.

`check_transfer.py` prints these lines and the 1% corners, and is the thing to
re-run after changing any value.

## Adjusting the compensation

The divider is flat when `R_top · C_top = R_bottom · C_bottom`, which here is

```
C_top = C_node / 14.96          (998 kΩ against R3 ∥ R4 = 66.7 kΩ)
```

`C_top` is `C1 + TC1`. **`C_node` is `C4` plus everything the layout adds** —
the amplifier's input, the clamp diode, the trimmer's own body, the traces, the
test point. That is the whole difficulty: the target moves with the layout, so
it cannot be settled before there is one.

What can be settled beforehand is that the trimmer's window contains the answer.
With `C1` at 5.6 pF and `TC1` 0.5–3 pF, `C_top` covers 6.1–8.6 pF, which is a
node stray of **9 to 47 pF** on top of `C4`'s 82 pF. A node with this many
things on it plausibly sits near the middle of that.

`C1` was 6.8 pF, which put the window at 7.3–9.8 pF and a stray of **27 to
65 pF**. A small board is unlikely to reach 27 pF, and below it the trimmer
bottoms out over-compensated with nowhere left to go. A breadboard would not
have caught it either — its stray is *larger* than a PCB's, which pushes the
answer up into the window and trims happily.

The firmware puts a square wave on GPIO22 for exactly this. Feed it into a
channel, set the ±25 V range, and adjust TC1 until the corners are square — the
same procedure as compensating a scope probe, and the same failure modes:
overshoot means too much capacitance across the input resistor, a slumped
leading edge means too little.

The signal is only 3.3 V into a ±25 V range, so put the display on a fine
volts-per-division setting to see the corner.

## The range switch only needs one throw

`U2A` connects `R8` to VMID or to nothing: `NO` goes to VMID and **`NC` is
deliberately unconnected**, which the netlist check asserts. That is an SPST
switch wearing an SPDT's package.

It matters for the count. Three channels need three switches, and a dual SPDT
gives two per package, so the board carries two of them with one half of `U3`
wasted. **A quad SPST would do all three in one package.** A one-range build
needs no switch at all — see below.

What the part actually has to do is undemanding, which is worth knowing before
paying for a premium one. `COM` sits at VMID whichever way the switch is thrown,
so it never sees a signal swing — only the ±0.62 mA that full scale pushes
through `R8`, and only whatever that current drops across the switch itself:

| On resistance | Gain | Error | Swing across the switch |
| ---: | ---: | ---: | ---: |
| 1 Ω | 4.7439 | −0.03% | ±0.6 mV |
| 7 Ω, about what is fitted | 4.7355 | −0.21% | ±4.3 mV |
| 50 Ω | 4.6765 | −1.45% | ±30.9 mV |
| 100 Ω | 4.6101 | −2.85% | ±61.8 mV |

Every one of those is a fixed gain error that a two-point calibration removes.
What a high on resistance really costs is drift, since it moves with
temperature; distortion it cannot cause, because there is no signal across it to
distort. Off-state leakage does not matter much either: `R8` is 2.67 kΩ, so a
nanoamp through it is 2.7 µV, where the same nanoamp at the divider node would
be 62.5 µV.

So the substitution list is long — a dual SPDT of any modern family, or better a
quad or dual SPST — provided it runs on 3.3 V and takes 3.3 V logic. Check the
pinout rather than assuming: dual SPDT switches are not all pin compatible.

## Ranges are switched, not jumpered

The range switch is driven from GPIO2, GPIO3 and GPIO4, so the application always
knows which range a channel is on, can offer per-range calibration, and can
change ranges without anyone touching the board.

This is deliberate. A pair of jumpers per channel is cheaper, but a jumper left
in the wrong place produces a reading that is wrong by a factor of five and
looks perfectly plausible, with nothing in software able to tell.

## Building it with one range instead of two

A bench that would rather have no switch at all can have **±15 V and nothing
else** — wide enough for a 12 V supply, which is what a single range has to
reach to be useful with students at it. It was nearly a board of its own before
the part list said otherwise: every part it needs is a part of rev A.

The whole difference is **`R8`: 15 kΩ instead of 2.67 kΩ**, wired permanently to
VMID instead of being taken there by `U2A`. That makes the gain stage ×1.667
rather than ×4.745. Both TS5A23159 packages come off, and GPIO2 and GPIO3 come
free.

| | Overall gain | Offset | Reads |
| --- | ---: | ---: | --- |
| `R8` 15 kΩ, one range | 0.104408 | 1.650858 V | −15.81 … +15.80 V |

15 kΩ rather than the 13.3 kΩ that would land on exactly ±15 V, because 1%
parts at their worst corner still have to clear 15 V: 13.3 kΩ falls to 14.90 V
there, 15 kΩ only to 15.67 V.

Everything in front of the gain stage stays exactly as rev A has it, and that is
deliberate. The fixed 1 MΩ attenuator is where the input protection lives, not
where the range is chosen, so none of it moves:

| Input | Divider node | |
| ---: | ---: | --- |
| ±15.8 V | 2.64 V | the top of the range |
| 25 V | 3.22 V | reads as clipped; the clamp is still idle |
| 26.3 V | 3.30 V | the clamp begins to conduct |
| 100 V | 7.92 V | the continuous rating, 96 µA through the clamp |

Sizing a single divider straight for ±15 V and dropping the gain stage would
give up all of that. Full scale would put the divider node **at the rail**, so
the clamp would sit on the edge of conduction at the top of the range with its
leakage in the measurement, instead of having 26 V of headroom in front of it.

### What the single range costs

One range this wide is 1.5 bits coarser on small signals than rev A's fine
range:

| | Span | One count |
| --- | ---: | ---: |
| One range, ±15 V | 31.6 V | 7.72 mV |
| rev A ±5 V | 11.1 V | 2.71 mV |
| rev A ±25 V | 52.7 V | 12.86 mV |

3.3 V logic still lands on about 430 counts and a line-level audio signal on
360, which is enough to teach with, and the firmware's box-car decimation puts
bits back on slow sweeps. It is worth knowing rather than discovering.

### Nothing changes in either application

The device has reported its own ranges since firmware 1.7, so a one-range build
answers with one entry and both front panels disable the range menu on their
own — the macOS panel already asks `ranges.count > 1` and the browser one
`frontEnd().length < 2`. It needs no host release to be read correctly, and no
board id of its own: what it reports is what it is.

### Earning a fixed capacitor instead of a trimmer

A trimmer on a teaching board is both a cost and something for a student to
turn, so a classroom build should not have one. That is affordable if the
compensation is made insensitive to the layout rather than adjustable for it.

The lever is `C4`. Whatever the layout adds lands on `C_node` beside it, so the
larger `C4` is, the smaller a fraction of `C_node` the unknown becomes:

| `C4` | `C_node` with 20 pF of stray | `C_top` | Input capacitance | Error if the stray is 10 pF out |
| ---: | ---: | ---: | ---: | ---: |
| 82 pF, rev A | 102 pF | 6.8 pF | 6.8 pF | 9.8% |
| 150 pF | 170 pF | 11.4 pF | 11.4 pF | 5.9% |
| **220 pF** | **240 pF** | **16.0 pF** | **16.0 pF** | **4.2%** |
| 470 pF | 490 pF | 32.8 pF | 32.8 pF | 2.0% |

`C_top` is what the probe tip sees, so the price of insensitivity is input
capacitance. A bench oscilloscope's input is 10 to 20 pF, which puts **220 pF
the sensible end of the trade**: 16 pF in and a compensation that a fixed part
can hold to a few per cent.

So a one-range classroom build: **`C4` 220 pF, and a fixed capacitor near 16 pF
in place of `C1`/`TC1`** — with the exact value taken from measuring the first
boards, not from this table. Fit a trimmer on the prototype run; fit the number it lands on
thereafter.

## Protection

| | |
| --- | --- |
| Continuous input | ±100 V, set by the 0805 resistors' working voltage |
| Absolute maximum | ±200 V, momentary |
| Fault current into the clamp | under 100 µA at 100 V, through 1 MΩ |

The 1 MΩ input is itself most of the protection: at 100 V the divider node
would sit at 7.9 V, the clamp diodes conduct, and the current they pass is
96 µA. D1/D2 are BAV199 for their nanoamp leakage — a general-purpose switching
diode leaks enough at temperature to shift the zero on the fine range.

The TVS footprints at the connectors are unpopulated. Their capacitance appears
directly across the input and would upset the compensation, so they go in only
after that has been measured with them fitted.

## Logic inputs

Eight inputs on GPIO6…GPIO13, each through 330 Ω. **3.3 V logic only.** The
series resistor limits the current into the RP2350's own clamp diodes to about
5 mA at 5 V, which the chip survives, but a 5 V system will still be loaded and
the levels are outside specification. There is no buffer and no level shifter on
this board; feeding it 5 V logic is a rev B question, not a "probably fine".

Optional 100 kΩ pulldowns can be populated to keep unused inputs from floating.
They are marked DNP in the schematic and do nothing while unpopulated.

## Connections to the Pico 2

| Signal | GPIO | Physical pin |
| --- | ---: | ---: |
| CH1 to converter | GPIO26 / ADC0 | 31 |
| CH2 to converter | GPIO27 / ADC1 | 32 |
| CH3 to converter | GPIO28 / ADC2 | 34 |
| Analogue ground | AGND | 33 |
| Converter reference | ADC_VREF | 35 |
| Front-end supply | 3V3(OUT) | 36 |
| CH1 range switch | GPIO2 | 4 |
| CH2 range switch | GPIO3 | 5 |
| CH3 range switch | GPIO4 | 6 |
| Logic D0…D7 | GPIO6…GPIO13 | 9,10,11,12,14,15,16,17 |
| Adjustable calibration output | GPIO22 | 29 |
| Signal generator | GPIO16…GPIO19 | 21,22,24,25 |
| Unused | GPIO0, GPIO1, GPIO5, GPIO14, GPIO15 | 1,2,7,19,20 |

The range controls are low so that the generator can have GPIO16–19 on every
board — one answer to where the sine is, whichever instrument is plugged in.
Firmware 1.13 moved them from GPIO4–6 to GPIO2–4 and the logic inputs from
GPIO8–15 to GPIO6–13, where the PL2407AFE already had both, so the logic
inputs are the same eight pins on every board too.
Its four pins are not connected to anything on the carrier: they are PWM
carriers, and want an RC apiece before they are voltages.

The op amp draws about 4 mA, so the whole board runs from 3V3(OUT).

## Third channel (firmware 1.5)

CH3 uses U1C for its gain stage and U4C for its filter. Its input is J10, a
2-pin header. R36–R43, C16–C19, TC3 and D3 repeat the CH1 input network; D7 is
the optional DNP TVS, and TP7 exposes the divider node. U3A switches its range;
C20 decouples U3. U3B has control tied low and signal pins left unconnected.
U1D continues to buffer VMID.

CH3 ADC is GPIO28 / J7.7 and its range control GPIO6 / J6.9. Test output is
GPIO22 / J7.12, through R35 to TP6. J8 remains unused.

The ADC scans only the channels enabled in the app. Maximum rates per channel
are 495 / 247 / 165 kSa/s with 1 / 2 / 3 checked. At maximum rate each
conversion is 2.02 µs after the previous one; the inputs are not sampled
simultaneously. Three-channel Nyquist frequency is about 82 kHz, so the
analogue filter must be evaluated at that rate as well as the faster modes.

## Separate chord generator

The diminished-chord generator runs on a separate Pico 2. The carrier has no
J8 or note-output circuitry. Firmware 1.5 adds CH3 on GPIO28; test output is
GPIO22 / TP6 and the three range controls are GPIO4/5/6 on J6. Logic GPIO8–15
is unchanged throughout.
See [`tools/pico2-chord`](../../tools/pico2-chord) for the standalone program.

This pin allocation supersedes firmware 1.2: rewire the logic and range signals
before using firmware 1.3 or later. Firmware 1.5 also requires moving the test
output off GPIO28 before GPIO28 is used as CH3. The software range gains are unchanged.

## Before fabrication

These measurements happen on the **first PCB run**, not before it. There is no
breadboard prototype of this board: a breadboard's stray capacitance is larger
and less predictable than a layout's, so the one number most worth having early
— the compensation — is the one it cannot give. The
[mini AFE](../mini-afe/) next door is a different, simpler front end, not a
prototype of this one.

1. Review the captured schematic and assigned footprints against the actual
   parts to be ordered. KiCad ERC currently passes; rerun it after edits.
2. Lay out, keeping the divider node small — it is the compensation.
3. DRC, Gerber review, BOM and CPL.
4. On the first boards, **measure** the frequency response in both ranges.
   Every number above is nominal.
5. Measure the Sallen-Key's actual corner and Q against the calculated
   40.2 kHz and 0.742. Capacitor tolerance moves Q, and a Q much above 0.8
   puts a peak in the passband just where the filter is supposed to be
   flattening out.
6. Check the clamp diodes' leakage at temperature on the ±5 V range, where a
   nanoamp through 62 kΩ is already visible.
7. Trim `TC1` against the square wave on GPIO22, and fit the value it lands on
   from the second run.

The current schematic is in `hardware/pilyzer-afe/kicad`.

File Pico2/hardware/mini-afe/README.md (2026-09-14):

# Mini AFE

One MCP6022 in front of a bare Pico 2, on a breadboard. It is not a prototype of
[the rev A front end](../pilyzer-afe/) — that board's three amplifiers are going
straight to a PCB. This is the smallest thing that makes a signal readable:
**impedance conversion, twice, with the two halves set up differently.**

Used with `PILYZER_BOARD_ID 0`, the build that puts the converter pins straight
on the inputs and reports one 0 – 3.3 V range.

## What it is

```
IN(dc) ───────────── U1A + ── out ── R1 1k ──┬── GPIO26  CH1
                                             └── C1 4.7n ── GND

IN(ac) ── C3 1.5u ──┬── R2 100k ── +3V3
                    ├── R3 100k ── GND
                    └── U1B + ── out ── R4 1k ──┬── GPIO27  CH2
                                                └── C4 4.7n ── GND
```

Both halves of the dual are used, so there is nothing to switch:

| | Sees | For |
| --- | --- | --- |
| **CH1** | the input direct, DC coupled, gain 1 | a signal already inside 0 – 3.3 V |
| **CH2** | the input through `C3`, biased to mid rail | a signal that swings about 0 V |

[`breadboard-30rows.svg`](breadboard-30rows.svg) is where every part goes on a
30-row board, hole by hole, with the Pico on rows 1–20 and the MCP6022 on 24–27.
**Two jumpers are not on it**: each amplifier's output has to reach its converter
pin — row 23 A–E to row 10 F–J for CH1, and row 23 F–J to row 9 F–J for CH2.

Ground is taken twice on purpose. Pin 18 feeds the left rail and pin 23 the
right, and **pin 33 — AGND, the pin the converter measures against — joins the
right rail too**, so the analogue returns sit next to it rather than reaching it
through the Pico's own plane. The two rails are then linked at row 1.

That link closes a loop, which is worth a sentence because it looks alarming and
is not: both of its ends are the same Pico ground, so there is no second
reference to circulate current between. What it can pick up is magnetic, and the
area is small — a 1 µT field at 50 Hz induces 3 µV in it, which is 0.004 of a
count, and a 10 µT field 0.04. The gain is a return path that does not depend on
a single pin's contact.

Either way the follower does the job that matters: a high impedance to whatever
is being measured, a low one to the converter. The RP2350's ADC wants to see
**under 10 kΩ**, and a source that cannot promise that reads low and drifts —
the multiplexer's charge carries between channels and drags a high-impedance
input with it.

Set the bias in the panel to match: **0 on CH1, mid rail on CH2**. The dotted
line then lands where the channel actually sits, and both readings stay the
volts the converter saw.

## The numbers

**Output RC — `R1`/`C1` and `R4`/`C4`, 33.9 kHz.** The only bandlimiting in
either path, and the same on both.

| | |
| ---: | ---: |
| 20 kHz | −1.3 dB |
| 33.9 kHz | −3.0 dB |
| 100 kHz | −9.9 dB |
| 123.7 kHz — Nyquist with 2 channels | −11.6 dB |

One pole is not an anti-alias filter; rev A has a second-order section at
40.2 kHz for that. What this one does is stop the converter's sampling capacitor
from hanging on an op amp output, where a switched capacitor makes some
amplifiers ring. Treat anything above 100 kHz as suspect.

**The AC channel's divider — 100 kΩ each side, so 50 kΩ at the node.** That one
number carries the channel:

| | |
| --- | --- |
| Low corner, with `C3` at 1.5 µF | **2.1 Hz** |
| Settling from cold | 75 ms, `C3` charging through the divider |
| Its own high corner, with 20 pF of stray | 159 kHz — **above** the output RC, so the RC decides |
| Input impedance | 50 kΩ, and that is the price |

That last line is the trade. 50 kΩ is light for a function generator or an op
amp output and heavy for a sensor or a divider tap, so **high-impedance things
go on CH1**, where the only load is the amplifier's own picoamps.

The divider used to be 1 MΩ a side, which put 500 kΩ at the node and rolled the
AC channel off at 15.9 kHz — below the output RC, so the two channels stopped
agreeing above about 10 kHz. At 100 kΩ they agree all the way out.

## The op amp is the one part that is not free choice

**MCP6022: rail to rail in and out, on 3.3 V.** Both halves of that matter. The
follower's input is the signal itself, so a part whose input common mode stops
short of the rails cannot see the top of the range; and its output goes at a
converter measuring 0 to 3.3 V, so an output that stops short throws the top
away.

The LM358 that was in the socket shows exactly this. Its output reaches about
1.5 V below the positive rail, so on 3.3 V it stops near 1.8 V and **the top
clips**.

| | Input common mode | Output | On 3.3 V |
| --- | --- | --- | --- |
| **MCP6022** | rail to rail | rail to rail | the whole range |
| LM358 | stops ~1.5 V below V+ | stops ~1.5 V below V+ | usable to about 1.8 V |

CMOS input matters too, because bias current flows through the divider's 50 kΩ
and lands in the reading as an offset: 1 pA is 0.05 µV and nothing, where the
LM358's 45 nA is 2.25 mV, which is 2.8 counts.

## Trying it before you wire it

[`falstad-mini-afe.txt`](falstad-mini-afe.txt) is this circuit for the
[Falstad simulator](https://www.falstad.com/circuit/circuitjs.html), which runs
in a browser with nothing to install.

**[Open it in the simulator](https://www.falstad.com/circuit/circuitjs.html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)**

Both channels are drawn, each from its own source, so the coupled one and the
direct one can be watched together. A 1 V sine arrives at the converter pins as
**1.65 ± 1.0 V on both** — 1.999 V peak to peak, centred on 1.648 and 1.650 V —
and at 20 kHz both read 1.720 V peak to peak, which is what a 33.9 kHz single
pole does to 2 V and is the point of moving the divider to 100 kΩ: the two
channels now fall off together.

`C3` carries an initial −1.65 V so the mid rail starts settled rather than
taking 75 ms to charge. The 2.1 Hz low corner stays arithmetic — a cycle that
long is longer than the simulation advances while it is being watched.

## What it cannot do

- **No protection.** The input reaches the op amp through a coupling capacitor
  or nothing at all. There is no 1 MΩ in front of it and no clamp, so the op
  amp's own input diodes are all there is: keep the input inside the supply.
  Rev A's 1 MΩ input is
  [what protection looks like](../pilyzer-afe/README.md#protection).
- **No attenuation.** Gain is 1 on both channels, so the range is the
  converter's range.
- **No calibration story.** There is nothing to calibrate: what the converter
  reads is what reached it. The bias setting is the only thing to get right, and
  it is per channel.
- **No third channel.** GPIO28 is free if one is wanted, but the dual is full.

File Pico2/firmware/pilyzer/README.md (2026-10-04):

# PiLyzer firmware

Turns a Raspberry Pi Pico 2 into the instrument the macOS application in this
repository talks to: three analogue channels, eight logic channels, and a bulk USB
endpoint carrying the protocol in `docs/protocol.md`.

## What runs where

| File | |
| --- | --- |
| `main.c` | reassembles request frames, streams answers back; never blocks |
| `analog.c` | converter → DMA → decimation → trigger search |
| `logic.c` | PIO capture, PIO trigger watch, exact edge search |
| `logic_capture.pio` | the two state machine programs |
| `trigger_filter.h` | optional trigger-only LPF, with fractional-code state |
| `usb_descriptors.c` | one vendor-specific interface, so macOS loads no driver |
| `pilyzer_protocol.h` | the wire structures, shared with the host by hand |

## The two ideas worth knowing

**Nothing is paced by software.** The converter free-runs at its own clock into
a hardware ring the DMA wraps by itself, and the processor's only job is to
decimate out of it. Sample intervals are therefore exact — they are a register,
not a `sleep_us` — and the host is told the register rather than a rounded
number, so the time axis on screen is right by construction.

**Decimation is an average, not a skip.** Every slow sample is the mean of all
the conversions underneath it. That is the anti-alias filter for slow sweeps, it
hands back the bits the averaging earns, and it means one code path covers
165 kSa/s and 4 Sa/s.

The logic side inverts the usual arrangement: a second state machine watches the
trigger pin at full clock speed, and the *processor* finds the exact edge
afterwards by looking through the captured bytes. So the trigger lands on a
sample even though nothing running on the processor could have seen it live.

## Memory

| | |
| --- | --- |
| Analogue record | 98 304 conversions, 192 KB |
| Converter ring | 4 096 conversions, 8 KB, wrapped by the DMA |
| Logic record | 131 072 samples, 128 KB |
| Code | about 32 KB |

Change these in `board_config.h`; the host reads the limits out of
`OP_CAPABILITIES` and follows. The original Pico has half the RAM, so its build
has half of each record: 49 152 conversions and 65 536 logic samples, which
is 12 288 points on two channels and 8 192 on three.

## Pins

| Signal | GPIO |
| --- | --- |
| CH1 | 26 (ADC0) |
| CH2 | 27 (ADC1) |
| CH3 | 28 (ADC2) |
| Logic D0…D7 | 6…13, consecutive because PIO reads them in one instruction |
| CH1 range switch | 2 |
| CH2 range switch | 3 |
| CH3 range switch | 4 |
| Signal generator | 16…19 (sine, white, pink, brown) |
| Adjustable calibration square wave | 22 |
| Unused pins | 0, 1, 5, 14, 15 |
| Status LED | the board's own |

On a bare Pico 2 with nothing else attached, CH1, CH2 and CH3 read 0 V to 3.3 V
directly and **must not go outside that**. The front end in
`hardware/pilyzer-afe` is what makes ±25 V safe.

### Three-channel acquisition (firmware 1.5)

CH3 uses GPIO28/ADC2 and GPIO6 for its range switch; the three range controls
are GPIO4/5/6, leaving GPIO16–19 to the generator. The adjustable test output
is GPIO22; `setCalibrationOutput` and the app's `Test output` still control it.
Firmware 1.13 moved logic to GPIO6–13 and the range controls to GPIO2–4, the
pins the PL2407AFE already used, so every board has the same logic inputs.

The enabled mask selects only the requested ADC inputs, in ascending order.
Any nonempty subset of CH1/CH2/CH3 is supported. At the fastest ADC clock the
per-channel ceilings are 494,845 / 247,423 / 164,948 samples/s for 1 / 2 / 3
channels — 48 MHz over the 97-cycle floor described above. The ADC multiplexes
channels; adjacent conversions are separated by 2.02 µs at maximum rate, not
simultaneous. Slower sweeps use decimation. Each
channel still supports a 16,384-point record with trigger history and tail room.

`analogSample` returns one 16-bit word per advertised analogue channel (six
bytes on firmware 1.5). Configuration and capability packet layouts are unchanged.

### Driverless on Windows too (firmware 1.6, working from 1.8)

A vendor-specific interface is what makes this driverless on macOS and Linux:
no kernel driver matches class `0xFF`, so an application claims the interface
itself. Windows works the other way round — it binds a driver *by name*, and
with no name it binds nothing, so the interface is visible but nothing can open
it, the browser application included.

So the device now names one for itself. `bcdUSB` is 2.1, which is what makes
Windows ask for the BOS descriptor at all, and the BOS carries two platform
capabilities: a Microsoft OS 2.0 descriptor set that declares the compatible id
`WINUSB` and a `DeviceInterfaceGUIDs` registry property, and a WebUSB
capability naming the hosted application as the landing page. Nothing has to be
installed by hand on any platform.

None of this changes a byte of the PiLyzer protocol; it is all in the enumeration
descriptors and two vendor control requests that never touch the bulk endpoints.

**Firmware 1.6 and 1.7 did not actually bind on Windows**, and 1.8 is the first
that does. The descriptor set carried its `WINUSB` compatible id inside a
configuration subset and a function subset, which is the shape a *composite*
device uses to hand different metadata to each of its functions. `usbccgp` is
what reads those subsets, and a device with a single interface never loads it,
so the compatible id was read by nobody: Windows saw a device that named no
driver and stopped at `CM_PROB_FAILED_INSTALL`. In 1.8 the compatible id and the
registry property sit directly under the set header, at device level, and the
descriptor set is 162 bytes rather than 178.

The bytes were self-consistent all along, which is why a host-side probe that
asked for the descriptor and checked its lengths reported it correct. Only
Windows could tell that they were in the wrong place.
### Over Wi-Fi, from a phone (Pico 2 W)

Safari has no WebUSB — not on iOS, not anywhere — so a phone cannot reach the
instrument the way a laptop does. A **Pico 2 W** can hand out the front panel
itself instead, over a network, and then any browser will do.

The released `PiLyzer-Pico2W.uf2` has no network in it. Copy it onto the Pico
2 W, connect it over USB, and give it your network from the **Wi-Fi** section
of the web application or the Mac app: network name, password, and the name it
should answer to. It keeps them in flash, where a firmware update leaves them,
and joins at once. The password is never read back.

Building it yourself works the same way:

```sh
cmake -S . -B build-w -G Ninja -DCMAKE_BUILD_TYPE=Release -DPILYZER_WIFI=ON
cmake --build build-w
```

`-DPILYZER_WIFI_SSID='your network' -DPILYZER_WIFI_PASSWORD='its password'`
bake a network in to start from instead, for a board that is never given one
over USB; one set over USB takes its place.

Then open **`http://pilyzer.local`**. There is no address to find and no
network to join: the instrument joins yours, answers to a name over mDNS, and
Safari resolves `.local` natively. The name is `-DPILYZER_HOSTNAME=` if one
instrument is not enough.

It answers over IPv6 as well (1.17): a Mac asks mDNS for both addresses, and
until the instrument had an IPv6 one to give, every visit waited five seconds
for the answer that never came. It keeps to its link-local address and takes no
global one from the router, so it is no easier to reach from outside the house
than it is on IPv4; the page and `/rpc` have no login.

The radio is **2.4 GHz only**, so name that network, not a 5 GHz one — on a
Buffalo router the `-G-` name rather than the `-A-` one. WPA2 and WPA3 both
work. The board's LED lights once it has an address and is serving the page;
until then it stays dark and the instrument keeps trying, every 40 seconds,
while USB carries on as usual.

Credentials baked in are cache variables, not files, so nothing of yours is in
the repository — but they are in the UF2, so a build made with them is not one
to hand out. Without `-DPILYZER_WIFI=ON` the build is exactly what it was —
`pico2`, no radio.

**How it works.** `bake-web.py` gzips the built application into flash, where
118,636 bytes become 40,839. A small server hands those out and answers
`POST /rpc` with the same packets USB carries — the protocol does not change,
so both applications and the golden fixtures are untouched. The request head is
parsed by `http_request.c`, which has no lwIP under it and a host test over it;
the socket in `http_server.c` is the part only hardware can check.

**What to expect of it.** The radio is roughly 1–2 Mbit/s against USB's
measured 1 MB/s, so a full three-channel record takes 0.4–0.8 s to come across
instead of 0.1. Single shots, the spectrum and the logger will not notice; a
free-running sweep will. USB is still there and still faster, and the
instrument works over it whether or not the network ever appears.

### A sine and three noises of its own (firmware 1.9)

`setSignals` puts a 440 Hz sine on GPIO0 and white, pink and brown noise on
GPIO1, 2 and 3 — enough to exercise a front end without a second board. Each is
a 586 kHz PWM carrier whose duty follows a sample, 50,000 a second, so **each
pin wants an RC** (1 kΩ and 10 nF) to come out as a voltage. All four sit on
mid rail and use about 2.8 V of the 3.3 V a pin can swing.

The generator costs one interrupt at 50 kHz. Acquisition is unaffected —
analogue capture is the converter and DMA, logic capture is PIO and DMA — but
it is switched off until the host asks, and the host is told whether the board
has it: the PL2407AFE switches its ranges on GPIO2–5, so board id 3 reports no
generator rather than fighting over the pins.

The same generator, in the same file, runs on a spare Pico 2 as
[`tools/pico2-noise`](../../tools/pico2-noise) for when the instrument's own
pins are wanted elsewhere.

Signal generators for a *separate* Pico 2 live in `tools`: the diminished chord
in [`tools/pico2-chord`](../../tools/pico2-chord), and a 440 Hz sine with white,
pink and brown noise in [`tools/pico2-noise`](../../tools/pico2-noise). Both use
GPIO0 upwards, which are unused on the instrument — but they are whole programs,
so a board runs one of them or PiLyzer, never two. The carrier has no J8.

## Without building

The [release](https://github.com/Satachito/Oscillo/releases/latest) carries a
UF2 for each board that needs no build options of its own:

| File | For |
| --- | --- |
| `PiLyzer-Pico2.uf2` | a Pico 2, bare or behind the mini AFE: board 0, one 0 – 3.3 V range |
| `PiLyzer-Pico2W.uf2` | a Pico 2 W, its network set from the application |
| `PiLyzer-PL2407AFE-Pico2.uf2` | a Pico 2 on picoLABO's PL2407AFE: board 3 |

Hold BOOTSEL while plugging the board in and copy the file onto the drive that
appears. None of them carries a network name or password. The PiLyzer AFE
(board 1) is built from source, below.

## Building

Needs the Pico SDK 2.x and an `arm-none-eabi` toolchain that includes newlib —
the Homebrew `arm-none-eabi-gcc` on its own does not, so point
`PICO_TOOLCHAIN_PATH` at the Arm-supplied toolchain if the link fails with
`cannot find -lc`.

```bash
./build.sh
```

which expects the SDK at `~/pico-sdk` and the toolchain at `~/arm-none-eabi`.
Override either with `PICO_SDK_PATH` or `PICO_TOOLCHAIN_PATH`:

```bash
PICO_SDK_PATH=/somewhere/else/pico-sdk ./build.sh
```

If you do not have the SDK yet:

```bash
git clone --recurse-submodules https://github.com/raspberrypi/pico-sdk ~/pico-sdk
```

Flash `build/pilyzer.uf2` with the board in BOOTSEL. After that the application
can put it back into BOOTSEL itself — the `rebootToBootloader` command — so the
button is only needed once.

Building for a board with the analogue front end fitted:

```bash
BOARD_ID=1 ./build.sh
```

Pass it as a CMake cache entry (`-DPILYZER_BOARD_ID=1`) if you are calling
CMake yourself. Do **not** set it through `CMAKE_C_FLAGS`: that replaces the
flags the SDK's own toolchain file puts there, and the SDK stops compiling.

The board id is what tells the application which input ranges exist, so a bare
Pico 2 offers one range of 0–3.3 V and a rev A board offers ±25 V and ±5 V.

### On the original Pico (firmware 1.19)

The same source builds for the original Raspberry Pi Pico (RP2040):

```bash
CHIP=rp2040 BOARD_ID=3 ./build.sh   # a PL2407AFE with an original Pico on it
```

`CHIP=rp2040` (CMake: `-DPILYZER_CHIP=rp2040`) picks the board and platform,
builds into `build-rp2040/`, and makes a UF2 for the RP2040's bootloader (its
drive is called RPI-RP2). It calls itself **PiLyzer Pico**. What differs is
what the chip has: half the record depth (above), a 125 MHz clock so the
logic analyser tops out at 125 MSa/s, and the sine generator's carrier at 488
kHz. There is no Wi-Fi build for it.

The RP2040's converter has uneven codes around 512, 1536, 2560 and 3584,
which the RP2350 fixed. Waveforms, frequencies and logic are as good as on a
Pico 2; a voltage reading near those codes, and the ENOB the spectrum
reports, are not.

## Bringing a board up

The acquisition boundary regressions also run on the host, without the Pico
SDK or an attached board:

```bash
./firmware/pilyzer/tests/run.sh  # from the repository root; requires Clang
```

These compile the production `analog.c` and `logic.c` against small substitutes
for the hardware calls. AddressSanitizer and UndefinedBehaviorSanitizer check
full buffers, late trigger edges, and safe re-arming. They do not validate DMA
or PIO timing on a physical board.

Firmware 1.2 adds **Trigger LPF** (Off or a cutoff in Hz). It filters the
comparator input while leaving the acquired samples intact. Tests also cover
filter settling, buffer rollover, preserved raw waveforms and a 194 Hz,
30-step signal with high-frequency ripple. The LPF requires the matching host
application; old hosts keep it off via the zero reserved field.

```bash
swift run PiLyzer --list       # is it on the bus, and is it an instrument?
swift run PiLyzer --selftest   # walk the whole command set and report
swift run PiLyzer --bootsel    # restart in the bootloader, ready for new firmware
swift run PiLyzer --rangecheck # every channel on every range, reading the test square
swift run PiLyzer --network    # a Pico 2 W's network: set or not, joined or not, its address
```

With more than one instrument plugged in, `--at 0x01100000` picks one by the
location `--list` prints. `--rangecheck` is for a front end just built: wire
the test square wave (GPIO22, or another PiLyzer's with the grounds joined)
to every input, and each range should read 0 V to 3.3 V at the same
frequency, cut off at its own limits where the square goes past them.

`--selftest` is the thing to run on a new board. It reads the identity and the
capabilities, takes an immediate sample, captures an analogue record, arms a
real trigger and checks that the edge is at the index the instrument reported,
and captures a logic record. Anything wrong below the front panel shows up
there rather than as a strange trace.

After the first flash the button is never needed again: `--bootsel` puts the
board back into its bootloader over USB, so the cycle is

```bash
./firmware/pilyzer/build.sh && swift run PiLyzer --bootsel && sleep 2 && \
  picotool load -x firmware/pilyzer/build/pilyzer.uf2
```

**The converter's fastest interval is 97 clocks, not 96.** A conversion takes
96, but the pacing register holds the interval minus one and the converter only
obeys it when that register is 96 or more. Asking for 96 writes 95, the pacing
is abandoned, and it free-runs at about twice the rate — while the plan still
reports the interval that was asked for. `swift run PiLyzer --timing` measures
this: before the fix a 1 kHz square read back as 2 kHz at the fastest sweep and
correctly at every slower one.

**Checking the time axis.** Nothing above proves the sample interval is right —
the samples alone cannot say how far apart they are. Put a jumper from GPIO22
(the test square wave) to GPIO26 (CH1) and the scope should read a 1 kHz square
wave with a 50% duty cycle. If the frequency reads correctly across several
sweep speeds, the whole timing chain is right; if it is wrong by a constant
factor, the divisor arithmetic in `analog.c` is where to look.

## Identity

VID:PID is **1209:0001** — pid.codes' identifier for prototypes that are not
shipped. Ask Raspberry Pi for a product id under 2E8A, or pid.codes for one of
your own, before this leaves the bench. The application checks the `PLYZ` magic
and the protocol version in the identify reply as well, so it will not mistake
another prototype on the same identifier for an instrument.

## What it does not do yet

* **Equivalent-time sampling.** The fastest real-time sweep is set by the
  converter: 4 µs per sample pair, so about 20 µs per division before the trace
  becomes dots. Building a record from many triggers would go far faster on a
  repetitive signal, and needs a programmable delay between the trigger and the
  start of capture.
* **A shared trigger between the analogue and logic sides.** Both run, but
  independently, so their records cannot be lined up against each other.
* **Pattern triggers on the logic inputs** — the watcher is one edge on one
  channel.
* **Streaming.** Records are captured and then read; there is no continuous
  mode, so the meter's rate is set by round trips.

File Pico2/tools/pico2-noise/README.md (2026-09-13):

# Four test signals on a Pico 2

A 440 Hz sine and three noises, on a Pico 2 with nothing else to do. Flash it
to a **spare board** — it is a separate program from
[`../pico2-chord`](../pico2-chord), and a Pico can only run one of them.

**The instrument does this itself**, from the same source file: switch on
Signal generator in the panel. It puts them on GPIO16–19 rather than the pins
below. This program is for when the instrument's own pins are wanted for
something else, or when a second board is simply more convenient than sharing
one.

| GPIO | Signal | Level (peak to peak) | RMS |
| ---: | --- | ---: | ---: |
| 0 | 440 Hz sine | 3.14 V | 1.11 V |
| 1 | white noise, flat | 2.96 V | 0.86 V |
| 2 | pink noise, −3 dB an octave | 2.82 V | 0.34 V |
| 3 | brown noise, −6 dB an octave | 2.76 V | 0.34 V |

All four sit on **1.65 V**, use 0–3.3 V and never reach either rail. Take the
reference from a GND pin on this board.

## Fit an RC on each pin

The RP2350 has no converter, so each signal is a **586 kHz PWM carrier whose
duty follows the sample**, 50,000 samples a second. Without a filter, a pin
carries square edges and the signal is only in their width:

```text
GPIO ──[ R ]──┬── to the instrument
              │
            [ C ]
              │
             GND
```

| R | C | Corner | Carrier left | Good for |
| ---: | ---: | ---: | ---: | --- |
| 1 kΩ | 100 nF | 1.6 kHz | −51 dB | the sine, and hearing the noises |
| 1 kΩ | 8.2 nF | 19 kHz | −30 dB | noise with its top octaves intact |

One pole is enough because the carrier is nine octaves above the signal. What
is left of it lands at 586 kHz, above anything PiLyzer samples — but **not
above what it aliases**: at 500 kSa/s a residual carrier folds back to 86 kHz,
so filter it rather than leave it.

## What the noises are

White comes from a 32-bit xorshift, which is uniform rather than Gaussian: its
peak is exactly its amplitude, so it can use nearly the whole range without
ever clipping. Pink is Paul Kellett's three-pole fit to a 3 dB per octave tilt.
Brown is white integrated, with a slow leak so it cannot wander onto a rail and
stay there.

The tests tell them apart without a spectrum analyser, by how much a sample
differs from the one before it against the signal's own power — 2 for
uncorrelated noise, and halving with each octave of tilt:

| | white | pink | brown |
| --- | ---: | ---: | ---: |
| measured | 2.00 | 0.37 | 0.011 |

## Building and flashing

From the repository root, with the Pico SDK and ARM toolchain configured:

```sh
cmake -S Pico2/tools/pico2-noise -B build/pico2-noise -G Ninja
cmake --build build/pico2-noise
bash Pico2/tools/pico2-noise/tests/run.sh
```

Hold BOOTSEL, plug the spare Pico 2 in, and copy `build/pico2-noise/noise.uf2`
onto the drive that appears. USB CDC prints the sample rate and the carrier;
the board LED blinks.

## Measuring it with PiLyzer

The signals are DC coupled and sit at mid rail, which is what the mini AFE in
front of the instrument wants: nothing on that board shifts them, so what the
converter reads is what this one made. 440 Hz is 113 samples at 50 kSa/s, so a
sweep of 1 ms/div holds four and a half cycles.

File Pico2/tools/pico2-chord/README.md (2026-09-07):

# Standalone diminished-chord generator

Run this program on a dedicated Pico 2, separate from the PiLyzer instrument.
It continuously emits 50% duty square waves with complementary levels on each
pair: even GPIO normal, odd GPIO inverted. UART stdio is disabled; USB CDC
prints actual PWM frequencies and the board LED blinks.

| Note | Normal GPIO | Inverted GPIO | Nominal frequency |
| --- | ---: | ---: | ---: |
| C4 | 0 | 1 | 261.626 Hz |
| E♭4 | 2 | 3 | 311.127 Hz |
| F♯4 | 4 | 5 | 369.994 Hz |
| A4 | 6 | 7 | 440.000 Hz |

Use a GND pin on this Pico as the signal reference. Signals are 0–3.3 V square
waves. Analogue sine-wave conversion and DC removal belong on a separate board.

The four PWM slices start together. Integer clock dividers and even periods
keep duty at 50% without fractional-divider modulation. At a nominal 150 MHz
system clock, the actual frequencies are 261.626690, 311.131023, 369.993981 and
440.001408 Hz; oscillator accuracy still applies.

From the repository root, with the Pico SDK and ARM toolchain configured:

```sh
cmake -S tools/pico2-chord -B build/pico2-chord -G Ninja
cmake --build build/pico2-chord
bash tools/pico2-chord/tests/run.sh
```

The output is `build/pico2-chord/chord.uf2`. This program is independent of the
instrument firmware and is not linked into it. The PiLyzer carrier has no J8.

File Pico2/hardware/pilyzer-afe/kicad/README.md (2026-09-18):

# PiLyzer AFE — KiCad project

Open **pilyzer-afe.kicad_pro** in **KiCad 10** and launch the schematic editor.
This deliverable includes schematic capture and footprint assignment. It has
no PCB layout or manufacturing files.

## Sheets and files

- `pilyzer-afe.kicad_sch`: Pico 2 sockets, logic inputs, power, VMID and test output.
- `channel-1.kicad_sch`, `channel-2.kicad_sch`, `channel-3.kicad_sch`: fixed input divider, gain stage,
  range switch, clamps and the Sallen-Key anti-alias filter.
- `PiLyzer.kicad_sym`, `PiLyzer.pretty`, and both library tables: local symbols
  and all 13 footprint types. No external library is needed for schematic or
  footprint editing. Optional 3D models use the standard KiCad model paths.
- `bom.csv`: all 93 physical components, including the 11 DNP parts.
- `previews/`: SVG exports of all four sheets.
- `erc.rpt`: KiCad 10.0.5 electrical-rule-check report.
- `check_kicad.py`: checks the saved circuit via KiCad's exported netlist.

## Capture decisions and corrections

The saved schematic takes precedence over the earlier ASCII sketch.

1. R8/R16/R43 are **2.67 kΩ**, following the BOM and `../check_transfer.py`; the old
   sketch's 2.49 kΩ was stale. The nominal fine-range gain remains 4.745.
2. C1/TC1, C8/TC2 and C16/TC3 span the **entire 998 kΩ** input resistance.
3. R7/R15/R42 return from the gain stage's own output, **before** the filter,
   so the range switching is not inside the filter's loop.
4. One **BAV199 dual-series diode per channel** supplies both rail clamps.
   D1/D2/D3 pin 1 = GND, pin 2 = 3V3, pin 3 = divider node. D3 now belongs
   to CH3; D4 remains unused. Optional connector TVS footprints D5/D6/D7 are
   marked DNP with no exact part selected.
5. U2A/U2B/U3A COM connects to the 2.67 kΩ resistor, NO to VMID, and NC is deliberately
   unconnected. GPIO2/3/4 LOW gives ±25 V; HIGH gives ±5 V, matching firmware
   switch positions 0/1. The TI DGS package uses the KiCad footprint
   `TSSOP-10_3x3mm_P0.5mm` (VSSOP-10, not a generic footprint selected by name).
6. C15 bypasses the **divider midpoint before U1D**, avoiding a direct 1 µF
   capacitive load on its output. U1C is the CH3 gain stage; U1D remains the VMID buffer.
7. **U4 is the anti-alias filter quad.** U4A/U4B/U4C are unity-gain Sallen-Key
   sections on the channel sheets — R5/R6, R13/R14 and R40/R41 as the equal
   2.67 kΩ pairs, C21/C22/C23 as feedback and C6/C10/C18 as the shunt to VMID,
   giving fc 40.2 kHz and Q 0.742. R44/R45/R46 isolate each output from the
   converter, C7/C11/C19 are the reservoir at the pin. U4D is a follower on
   VMID rather than a floating input, U4E is the supply unit, and C24 decouples
   it. Inputs are the 2-pin headers J3/J4/J10; the BNC footprints are gone.
8. Both Pico socket pad-1 ends face USB. J6 pad 1 = physical Pico pin 1;
   J7 pad 1 = physical Pico pin 40. The right socket maps in reverse physical
   pin order. Socket rows must be 17.78 mm apart in the future PCB layout.
8. C12 decouples U1, C13 decouples U2, C20 decouples U3; all use Pico 3V3(OUT). Pico AGND
   and ground are one net. ADC_VREF is left unconnected on the carrier.
9. R27–R34 are DNP. They suppress floating logic inputs only when populated.

## Pin map

| Signal | GPIO | Pico physical pin | Carrier socket pad |
| --- | ---: | ---: | --- |
| CH1 ADC | 26 | 31 | J7.10 |
| CH2 ADC | 27 | 32 | J7.9 |
| CH3 ADC | 28 | 34 | J7.7 |
| CH1 range | 4 | 6 | J6.6 |
| CH2 range | 5 | 7 | J6.7 |
| CH3 range | 6 | 9 | J6.9 |
| Test output | 22 | 29 | J7.12 |

The three range nets were on J7.20 / J7.19 / J7.17 and the square wave on
J7.15 until firmware 1.11 and 1.12 moved them; those pads, with J7.16, are
GPIO16–19 and belong to the signal generator now, and carry no-connect flags.

Firmware 1.13 moved logic D0–D7 to GPIO6–13 (J6.9–J6.17) and the range nets
to GPIO2/3/4 (J6.4–J6.6), matching the PL2407AFE. GPIO0, 1, 5, 14 and 15
(J6.1, 2, 7, 19, 20) are unconnected, as are the
four generator pins on the carrier. J8 is unused:
CH3's input is J10, and the diminished-chord generator stays on a separate
Pico 2.
U3A is CH3's range switch; U3B control is grounded and its signal pins are NC.

The check script verifies the three complete analogue paths, unused pins,
active GPIO map against firmware macros, and every assigned footprint.
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

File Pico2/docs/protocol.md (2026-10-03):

# PiLyzer wire protocol, version 1

This is the contract between the RP2350 firmware (`firmware/pilyzer`) and the
macOS application (`Sources/PiLyzerCore`). It carries no inheritance from the
DPScope SE: nothing here describes a register of a particular microcontroller.
The host asks for *what it wants* — a sample period, a record length, a trigger
condition — and the device answers with *what it will actually do*. Every axis
the application draws is labelled from the device's answer, never from a
constant compiled into the host.
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

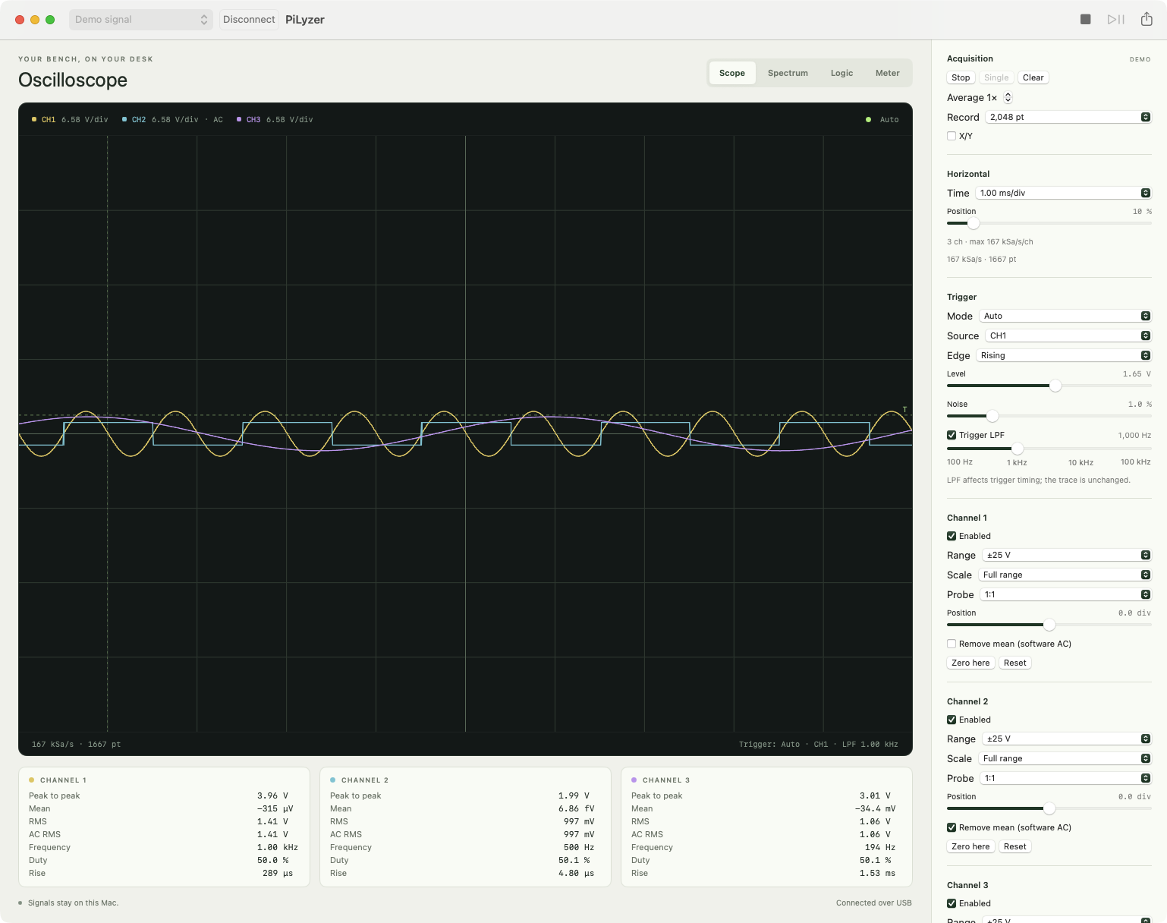
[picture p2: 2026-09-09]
Pico2/screenshot.png

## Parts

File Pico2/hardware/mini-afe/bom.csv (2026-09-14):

Item | Value | Qty | Package | Designator | Notes
Op amp | MCP6022-I/P | 1 | DIP-8 | U1 | Dual, and both halves are used: A is the direct channel (CH1), B the AC one (CH2). Rail to rail in and out — see the README before substituting.
Resistor | 100k 1% metal film | 2 | Through hole | R2 R3 | Bias divider to mid rail, on the AC channel only. 50 kΩ at the node.
Capacitor | 1.5uF (155) | 1 | Through hole | C3 | Coupling capacitor on the AC channel. With the divider this is 2.1 Hz. If it is electrolytic, + goes to the divider node.
Resistor | 1k 1% metal film | 2 | Through hole | R1 R4 | One at each op amp output: R1 to GPIO26, R4 to GPIO27.
Capacitor | 4.7nF C0G/NP0 | 2 | Through hole | C1 C4 | With R1/R4: 33.9 kHz. Also keeps the converter's sampling capacitor off the op amp outputs.
Capacitor | 100nF X7R | 1 | Through hole | C2 | Op amp decoupling. At the supply pin.
Breadboard | 830 tie point or larger | 1
Jumper wire | Assorted | 1 set

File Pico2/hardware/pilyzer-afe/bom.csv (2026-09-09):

Designator | Value | Part | Footprint | Qty | Notes
R1 R2 R9 R10 R36 R37 | 499k 1% |  | R_0805_2012Metric | 6 | Input resistor split in two so each sees half the voltage
R3 R11 R38 | 125k 1% |  | R_0805_2012Metric | 3 | Bias leg to 3V3; smaller than R4 on purpose
R4 R12 R39 | 143k 1% |  | R_0805_2012Metric | 3 | Bias leg to AGND
R5 R6 R13 R14 R40 R41 | 2.67k 1% |  | R_0805_2012Metric | 6 | Sallen-Key series resistors, equal pair
R7 R15 R42 | 10k 0.1% |  | R_0805_2012Metric | 3 | Gain stage feedback
R8 R16 R43 | 2.67k 0.1% |  | R_0805_2012Metric | 3 | Gain stage, switched to VMID for the fine range; sized so 1% parts still cannot push the range past the converter
R17 R18 | 10k 0.1% |  | R_0805_2012Metric | 2 | VMID divider from 3V3
R19-R26 | 330R 1% |  | R_0805_2012Metric | 8 | Logic input series protection
R27-R34 | 100k DNP |  | R_0805_2012Metric | 8 | Optional logic pulldowns
R35 | 100R 1% |  | R_0805_2012Metric | 1 | Test output series
C1 C8 C16 | 5.6pF C0G |  | C_0603_1608Metric | 3 | Divider compensation; pairs with C4. Sized so the trimmer's window straddles a plausible node stray — see the README.
TC1 TC2 TC3 | 0.5-3pF trimmer |  | C_Trimmer_Murata_TZC3 | 3 | Compensation adjustment against the test square wave
C4 C9 C17 | 82pF C0G |  | C_0603_1608Metric | 3 | Sets the node capacitance the compensation is computed from
C6 C7 C10 C11 C18 C19 | 1nF C0G |  | C_0603_1608Metric | 6 | Sallen-Key shunt to VMID, and the reservoir at the converter pin
C12 C13 C20 | 100nF X7R |  | C_0603_1608Metric | 3 | U1/U2/U3 decoupling
C14 | 10uF X7R |  | C_0805_2012Metric | 1 | Board bulk
C15 | 1uF X7R |  | C_0603_1608Metric | 1 | VMID divider bypass, before U1D buffer
U1 | TLV9064IDR | Quad RRIO 10MHz op amp | SOIC-14_3.9x8.7mm_P1.27mm | 1 | Three gain stages and one VMID buffer
U2 U3 | TS5A23159DGSR | Dual SPDT analogue switch | TSSOP-10_3x3mm_P0.5mm | 2 | Three range switches; unused U3B control grounded and signal pins NC
D1 D2 D3 | BAV199 | Low-leakage dual diode | SOT-23 | 3 | One dual-series package per node; pin 1 GND / pin 2 3V3 / pin 3 node
D5 D6 D7 | ESD low-cap TVS DNP |  | SOD-323 | 3 | Fit only after measuring what it does to the compensation
J3 J4 J10 | 1x2 header |  | PinHeader_1x02_P2.54mm_Vertical | 3 | Analogue inputs
J5 | 1x10 header |  | PinHeader_1x10_P2.54mm_Vertical | 1 | Logic D0-D7 plus two grounds
J6 J7 | 1x20 socket |  | PinSocket_1x20_P2.54mm_Vertical | 2 | Pico 2
TP1-TP7 | Test point |  | TestPoint_Plated_Hole_D2.0mm | 7 | CH1 node, CH2 node, VMID, 3V3, AGND, test output, CH3 node
R44 R45 R46 | 1k 1% |  | R_0805_2012Metric | 3 | Isolates the filter output from the converter sampling capacitor
C21 C22 C23 | 2.2nF C0G |  | C_0603_1608Metric | 3 | Sallen-Key feedback capacitor; sets Q with the 1 nF shunt
U4 | TLV9064IDR | Quad RRIO 10MHz op amp | SOIC-14_3.9x8.7mm_P1.27mm | 1 | Three anti-alias filters; U4D unused, input tied to VMID
C24 | 100nF X7R |  | C_0603_1608Metric | 1 | U4 decoupling

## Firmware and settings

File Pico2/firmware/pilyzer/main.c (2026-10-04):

// PiLyzer — a two-channel oscilloscope, spectrum analyser front end and eight
// channel logic analyser on a Raspberry Pi Pico 2.
//
// This file is only the conversation with the host: it reassembles request
// frames from the bulk endpoint, hands them to the acquisition modules, and
// streams the answers back. Nothing here blocks, so the decimator in analog.c
// and the trigger watch in logic.c keep running while a record is being sent.

#include <string.h>

#include "analog.h"
#include "board_config.h"
#include "hardware/clocks.h"
#include "hardware/gpio.h"
#include "hardware/pwm.h"
#include "logic.h"
#include "pico/bootrom.h"
#include "pico/stdlib.h"
#include "pilyzer_protocol.h"
#include "signals.h"
#if PILYZER_WIFI
#include "wifi.h"
#endif
#include "tusb.h"

// The longest request is OP_SET_NETWORK's 128 bytes, and the longest inline
// reply OP_NETWORK_STATUS's 72.
#define MAX_REQUEST_PAYLOAD 128

// --- Outgoing frames ----------------------------------------------------
// A response is a header, optionally a small inline payload, and optionally a
// large body that points straight into an acquisition buffer — records are
// never copied on their way out.
static uint8_t  tx_head[PILYZER_HEADER_SIZE + MAX_REQUEST_PAYLOAD];
static uint32_t tx_head_sent;
static uint32_t tx_head_size;
static const uint8_t *tx_body;
static uint32_t tx_body_sent;
static uint32_t tx_body_size;
static bool     reboot_when_drained;

// How long a response may make no progress before it is abandoned. The host's
// own transfer timeouts are a second or two, so nothing that is still being
// waited for is thrown away.
#define TX_ABANDON_MS 2500

static uint32_t tx_last_progress_ms;

static bool transmitting(void)
{
    return tx_head_sent < tx_head_size || tx_body_sent < tx_body_size;
}

// Forgets whatever was being said and starts listening again.
//
// A host that is killed mid-exchange leaves an answer nobody will ever read.
// Without this the transmit buffer stays full, the receive buffer fills behind
// it, the endpoint stops accepting anything, and the instrument needs its power
// removed before it will talk again.
static void abandon_exchange(void)
{
    tx_head_size = 0;
    tx_head_sent = 0;
    tx_body_size = 0;
    tx_body_sent = 0;
    tx_body = NULL;
    tud_vendor_read_flush();
}

static void respond(uint8_t opcode, uint16_t sequence, uint8_t status,
                    const void *inline_payload, uint32_t inline_size,
                    const uint8_t *body, uint32_t body_size)
{
    pilyzer_header_t header = {
        .magic = PILYZER_MAGIC_RESPONSE,
        .opcode = opcode,
        .status = status,
        .flags = 0,
        .sequence = sequence,
        .reserved = 0,
        .length = inline_size + body_size,
    };
    memcpy(tx_head, &header, sizeof header);
    if (inline_size) memcpy(tx_head + PILYZER_HEADER_SIZE, inline_payload, inline_size);

    tx_head_size = PILYZER_HEADER_SIZE + inline_size;
    tx_head_sent = 0;
    tx_body = body;
    tx_body_size = body ? body_size : 0;
    tx_body_sent = 0;
}

static void pump_transmit(void)
{
    uint32_t before = tx_head_sent + tx_body_sent;

    while (tx_head_sent < tx_head_size) {
        uint32_t written = tud_vendor_write(tx_head + tx_head_sent, tx_head_size - tx_head_sent);
        if (written == 0) break;
        tx_head_sent += written;
    }
    if (tx_head_sent == tx_head_size) {
        while (tx_body_sent < tx_body_size) {
            uint32_t written = tud_vendor_write(tx_body + tx_body_sent, tx_body_size - tx_body_sent);
            if (written == 0) break;
            tx_body_sent += written;
        }
    }
    tud_vendor_write_flush();

    if (!transmitting()) { tx_last_progress_ms = 0; return; }

    uint32_t now = to_ms_since_boot(get_absolute_time());
    if (tx_last_progress_ms == 0 || tx_head_sent + tx_body_sent != before) {
        tx_last_progress_ms = now;
    } else if (now - tx_last_progress_ms > TX_ABANDON_MS) {
        abandon_exchange();
        tx_last_progress_ms = 0;
    }
}

// --- Peripherals the host can poke --------------------------------------

static void set_led(bool on)
{
#ifdef PICO_DEFAULT_LED_PIN
    gpio_put(PICO_DEFAULT_LED_PIN, on);
#else
    (void)on;
#endif
}

static uint8_t range_pin(uint8_t channel)
{
    static const uint8_t pins[] = {PIN_RANGE_CH1, PIN_RANGE_CH2, PIN_RANGE_CH3};
    return pins[channel];
}

static void set_input_range(uint8_t channel, uint8_t position)
{
#if PILYZER_BOARD_ID == 3
    // Break before make: start at the widest range before enabling a bypass.
    gpio_put(range_pin(channel), false);
    gpio_put(range_pin(channel) + 1, false);
    if (position == 1) gpio_put(range_pin(channel) + 1, true);
    if (position == 2) gpio_put(range_pin(channel), true);
#else
    gpio_put(range_pin(channel), position != 0);
#endif
}

static uint32_t set_calibration_output(bool on, uint32_t frequency_hz)
{
    uint slice = pwm_gpio_to_slice_num(PIN_CALIBRATION_OUT);
    uint channel = pwm_gpio_to_channel(PIN_CALIBRATION_OUT);

    if (!on) {
        pwm_set_enabled(slice, false);
        gpio_set_function(PIN_CALIBRATION_OUT, GPIO_FUNC_SIO);
        gpio_set_dir(PIN_CALIBRATION_OUT, GPIO_OUT);
        gpio_put(PIN_CALIBRATION_OUT, 0);
        return 0;
    }

    if (frequency_hz == 0) frequency_hz = 1000;
    uint32_t system_hz = clock_get_hz(clk_sys);
    if (frequency_hz > system_hz / 4) frequency_hz = system_hz / 4;

    uint32_t counts = system_hz / frequency_hz;
    uint32_t divider = counts / 65536u + 1u;
    if (divider > 255) divider = 255;
    uint32_t wrap = counts / divider;
    if (wrap < 2) wrap = 2;
    if (wrap > 65536) wrap = 65536;

    gpio_set_function(PIN_CALIBRATION_OUT, GPIO_FUNC_PWM);
    pwm_set_clkdiv_int_frac(slice, (uint8_t)divider, 0);
    pwm_set_wrap(slice, (uint16_t)(wrap - 1));
    pwm_set_chan_level(slice, channel, (uint16_t)(wrap / 2));
    pwm_set_enabled(slice, true);
    return system_hz / (divider * wrap);
}

// --- Request handling ---------------------------------------------------

static void fill_identity(pilyzer_identity_t *identity)
{
    memset(identity, 0, sizeof *identity);
    identity->magic = PILYZER_IDENTITY_MAGIC;
    identity->protocol_version = PILYZER_PROTOCOL_VERSION;
    identity->firmware_version = PILYZER_FIRMWARE_VERSION;
    identity->board_id = PILYZER_BOARD_ID;
    memcpy(identity->name, PILYZER_PRODUCT_NAME, sizeof PILYZER_PRODUCT_NAME - 1);
}

static void fill_capabilities(pilyzer_capabilities_t *capabilities)
{
    memset(capabilities, 0, sizeof *capabilities);
    capabilities->analog_channels = ANALOG_CHANNELS;
    // The converter's own width. Samples are left-aligned into 16 bits and
    // decimation fills in below, so the host derives full scale from this.
    capabilities->analog_bits = 12;
    capabilities->logic_channels = LOGIC_CHANNELS;
    capabilities->analog_ranges = ANALOG_RANGES;
    capabilities->analog_clock_hz = ADC_CLOCK_HZ;
    capabilities->analog_min_period_cycles = ADC_MIN_PERIOD_CYCLES;
    capabilities->analog_max_record = ANALOG_MAX_RECORD;
    capabilities->analog_max_pretrigger = ANALOG_MAX_RECORD - 1;
    capabilities->logic_clock_hz = logic_clock_hz();
    capabilities->logic_max_record = LOGIC_MAX_RECORD;
    capabilities->logic_max_pretrigger = LOGIC_MAX_RECORD - 1;
    capabilities->reference_microvolts = ADC_REFERENCE_MICROVOLTS;
    // Only a board with a switch on it claims to switch ranges under software
    // control. A bare Pico 2 has one range because there is nothing in front of
    // it, and a rev A built with its gain leg wired rather than switched has
    // one for the same kind of reason.
    capabilities->flags = CAP_CALIBRATION_OUTPUT | CAP_TRIGGER_LOWPASS |
                          CAP_REPORTS_RANGES |
                          (ANALOG_RANGES > 1 ? CAP_SOFTWARE_RANGE : 0) |
                          (signals_available() ? CAP_SIGNAL_GENERATOR : 0)
#if PILYZER_WIFI
                          | CAP_NETWORK
#endif
                          ;
}

// What this board's front end does to a voltage on its way to the converter.
// The host draws its volts axis from these rather than from a table of its own
// keyed on the board id.
static const pilyzer_input_range_t input_ranges[ANALOG_RANGES] = PILYZER_INPUT_RANGES;

_Static_assert(sizeof(pilyzer_input_range_t) == 32,
               "an input range descriptor is 32 bytes on the wire");
_Static_assert(sizeof input_ranges / sizeof input_ranges[0] == ANALOG_RANGES,
               "the range table and ANALOG_RANGES disagree");

static void handle(const pilyzer_header_t *header, const uint8_t *payload)
{
    const uint8_t opcode = header->opcode;
    const uint16_t sequence = header->sequence;
    const uint32_t length = header->length;

    switch (opcode) {
    case OP_IDENTIFY: {
        pilyzer_identity_t identity;
        fill_identity(&identity);
        respond(opcode, sequence, ST_OK, &identity, sizeof identity, NULL, 0);
        return;
    }
    case OP_CAPABILITIES: {
        pilyzer_capabilities_t capabilities;
        fill_capabilities(&capabilities);
        respond(opcode, sequence, ST_OK, &capabilities, sizeof capabilities, NULL, 0);
        return;
    }
    case OP_INPUT_RANGES:
        respond(opcode, sequence, ST_OK, NULL, 0,
                (const uint8_t *)input_ranges, sizeof input_ranges);
        return;
    case OP_SET_LED:
        if (length < 1) { respond(opcode, sequence, ST_BAD_LENGTH, NULL, 0, NULL, 0); return; }
        set_led(payload[0] != 0);
        respond(opcode, sequence, ST_OK, NULL, 0, NULL, 0);
        return;

    case OP_SET_RANGE:
        if (length < 2) { respond(opcode, sequence, ST_BAD_LENGTH, NULL, 0, NULL, 0); return; }
        if (payload[0] >= ANALOG_CHANNELS || payload[1] >= ANALOG_RANGES) {
            respond(opcode, sequence, ST_BAD_ARGUMENT, NULL, 0, NULL, 0);
            return;
        }
        set_input_range(payload[0], payload[1]);
        respond(opcode, sequence, ST_OK, NULL, 0, NULL, 0);
        return;

    case OP_SET_CALIBRATION_OUT: {
        if (length < 5) { respond(opcode, sequence, ST_BAD_LENGTH, NULL, 0, NULL, 0); return; }
        uint32_t requested;
        memcpy(&requested, payload + 1, sizeof requested);
        uint32_t actual = set_calibration_output(payload[0] != 0, requested);
        respond(opcode, sequence, ST_OK, &actual, sizeof actual, NULL, 0);
        return;
    }
    case OP_SET_SIGNALS: {
        if (length < 5) { respond(opcode, sequence, ST_BAD_LENGTH, NULL, 0, NULL, 0); return; }
        if (!signals_available()) { respond(opcode, sequence, ST_BAD_ARGUMENT, NULL, 0, NULL, 0); return; }
        uint32_t requested;
        memcpy(&requested, payload + 1, sizeof requested);
        uint32_t actual = signals_set(payload[0] != 0, requested);
        respond(opcode, sequence, ST_OK, &actual, sizeof actual, NULL, 0);
        return;
    }
#if PILYZER_WIFI
    case OP_SET_NETWORK: {
        if (length < sizeof(pilyzer_network_config_t)) {
            respond(opcode, sequence, ST_BAD_LENGTH, NULL, 0, NULL, 0);
            return;
        }
        pilyzer_network_config_t config;
        memcpy(&config, payload, sizeof config);
        respond(opcode, sequence, wifi_configure(&config), NULL, 0, NULL, 0);
        return;
    }
    case OP_NETWORK_STATUS: {
        pilyzer_network_status_t status;
        wifi_status(&status);
        respond(opcode, sequence, ST_OK, &status, sizeof status, NULL, 0);
        return;
    }
#endif
    case OP_REBOOT_BOOTLOADER:
        respond(opcode, sequence, ST_OK, NULL, 0, NULL, 0);
        reboot_when_drained = true;
        return;

    case OP_ANALOG_CONFIGURE: {
        if (length < sizeof(pilyzer_analog_config_t)) {
            respond(opcode, sequence, ST_BAD_LENGTH, NULL, 0, NULL, 0);
            return;
        }
        pilyzer_analog_config_t config;
        memcpy(&config, payload, sizeof config);
        pilyzer_plan_t plan;
        uint8_t status = analog_configure(&config, &plan);
        respond(opcode, sequence, status,
                status == ST_OK ? &plan : NULL, status == ST_OK ? sizeof plan : 0, NULL, 0);
        return;
    }
    case OP_ANALOG_ARM:
        respond(opcode, sequence, analog_arm(), NULL, 0, NULL, 0);
        return;

    case OP_ANALOG_STATUS: {
        pilyzer_acq_status_t status;
        analog_status(&status);
        respond(opcode, sequence, ST_OK, &status, sizeof status, NULL, 0);
        return;
    }
    case OP_ANALOG_READ: {
        if (length < sizeof(pilyzer_read_request_t)) {
            respond(opcode, sequence, ST_BAD_LENGTH, NULL, 0, NULL, 0);
            return;
        }
        pilyzer_read_request_t request;
        memcpy(&request, payload, sizeof request);
        uint8_t channels = 1;
        uint32_t count = request.count;
        const uint16_t *samples = analog_record(request.offset, &count, &channels);
        uint32_t ceiling = PILYZER_MAX_PAYLOAD / (channels * 2u);
        if (count > ceiling) count = ceiling;
        respond(opcode, sequence, ST_OK, NULL, 0,
                (const uint8_t *)samples, count * channels * 2u);
        return;
    }
    case OP_ANALOG_ABORT:
        analog_abort();
        respond(opcode, sequence, ST_OK, NULL, 0, NULL, 0);
        return;

    case OP_ANALOG_SAMPLE: {
        if (!analog_idle()) { respond(opcode, sequence, ST_BUSY, NULL, 0, NULL, 0); return; }
        uint16_t averages = 1;
        if (length >= 2) memcpy(&averages, payload, sizeof averages);
        uint16_t reading[ANALOG_CHANNELS];
        analog_immediate(averages, reading);
        respond(opcode, sequence, ST_OK, reading, sizeof reading, NULL, 0);
        return;
    }

    case OP_LOGIC_CONFIGURE: {
        if (length < sizeof(pilyzer_logic_config_t)) {
            respond(opcode, sequence, ST_BAD_LENGTH, NULL, 0, NULL, 0);
            return;
        }
        pilyzer_logic_config_t config;
        memcpy(&config, payload, sizeof config);
        pilyzer_plan_t plan;
        uint8_t status = logic_configure(&config, &plan);
        respond(opcode, sequence, status,
                status == ST_OK ? &plan : NULL, status == ST_OK ? sizeof plan : 0, NULL, 0);
        return;
    }
    case OP_LOGIC_ARM:
        respond(opcode, sequence, logic_arm(), NULL, 0, NULL, 0);
        return;

    case OP_LOGIC_STATUS: {
        pilyzer_acq_status_t status;
        logic_status(&status);
        respond(opcode, sequence, ST_OK, &status, sizeof status, NULL, 0);
        return;
    }
    case OP_LOGIC_READ: {
        if (length < sizeof(pilyzer_read_request_t)) {
            respond(opcode, sequence, ST_BAD_LENGTH, NULL, 0, NULL, 0);
            return;
        }
        pilyzer_read_request_t request;
        memcpy(&request, payload, sizeof request);
        uint32_t count = request.count;
        if (count > PILYZER_MAX_PAYLOAD) count = PILYZER_MAX_PAYLOAD;
        const uint8_t *samples = logic_record(request.offset, &count);
        respond(opcode, sequence, ST_OK, NULL, 0, samples, count);
        return;
    }
    case OP_LOGIC_ABORT:
        logic_abort();
        respond(opcode, sequence, ST_OK, NULL, 0, NULL, 0);
        return;

    default:
        respond(opcode, sequence, ST_UNKNOWN_OPCODE, NULL, 0, NULL, 0);
        return;
    }
}

// --- Incoming frames ----------------------------------------------------

static uint8_t  rx_header_bytes[PILYZER_HEADER_SIZE];
static uint32_t rx_header_have;
static pilyzer_header_t rx_header;
static bool     rx_header_complete;
static uint8_t  rx_payload[MAX_REQUEST_PAYLOAD];
static uint32_t rx_payload_have;
static uint32_t rx_discard;

static void reset_receiver(void)
{
    rx_header_have = 0;
    rx_payload_have = 0;
    rx_header_complete = false;
}

// The link went away and came back — a replug, or the host asking for a
// re-enumeration to get an unresponsive instrument back. Either way nothing
// that was in flight means anything now.
void tud_mount_cb(void)
{
    abandon_exchange();
    reset_receiver();
    rx_discard = 0;
    tx_last_progress_ms = 0;
}

void tud_umount_cb(void)
{
    tud_mount_cb();
    analog_abort();
    logic_abort();
}

// Runs one request and hands back the reply, for a transport that frames its
// own messages and so needs none of the byte-stream machinery above.
//
// The command layer never knew what was carrying it: `handle` fills the same
// two buffers whoever asks, and a caller here reads them instead of pumping
// them at an endpoint. Refuses while USB is mid-answer, because both would be
// writing the same buffers.
bool pilyzer_execute(const uint8_t *packet, uint32_t length,
                     const uint8_t **head, uint32_t *head_size,
                     const uint8_t **body, uint32_t *body_size)
{
    if (transmitting()) return false;
    if (length < PILYZER_HEADER_SIZE) return false;

    pilyzer_header_t header;
    memcpy(&header, packet, PILYZER_HEADER_SIZE);
    if (header.magic != PILYZER_MAGIC_REQUEST) return false;
    if (header.length > MAX_REQUEST_PAYLOAD) return false;
    if (length != PILYZER_HEADER_SIZE + header.length) return false;

    handle(&header, packet + PILYZER_HEADER_SIZE);

    *head = tx_head;   *head_size = tx_head_size;
    *body = tx_body;   *body_size = tx_body_size;
    // The answer leaves with the caller, so nothing is left queued behind it.
    tx_head_sent = tx_head_size;
    tx_body_sent = tx_body_size;
    return true;
}

static void pump_receive(void)
{
    // One exchange at a time: nothing new is parsed while an answer is still
    // going out, which is what lets a response body point into a live buffer.
    if (transmitting()) return;

    while (tud_vendor_available()) {
        if (rx_discard) {
            uint8_t scratch[64];
            uint32_t want = rx_discard < sizeof scratch ? rx_discard : sizeof scratch;
            rx_discard -= tud_vendor_read(scratch, want);
            continue;
        }

        if (!rx_header_complete) {
            uint32_t got = tud_vendor_read(rx_header_bytes + rx_header_have,
                                           PILYZER_HEADER_SIZE - rx_header_have);
            rx_header_have += got;
            if (rx_header_have < PILYZER_HEADER_SIZE) return;

            memcpy(&rx_header, rx_header_bytes, sizeof rx_header);
            rx_header_complete = true;
            rx_payload_have = 0;

            if (rx_header.magic != PILYZER_MAGIC_REQUEST) {
                // Out of step with the host: throw away everything queued and
                // start looking for a header again.
                //
                // The flush is the part that matters. This is a byte stream, so
                // a request whose length field disagrees with the bytes that
                // followed it leaves the difference in the pipe, and every
                // header read after that starts in the wrong place. Clearing
                // the counters alone would keep reading from the same wrong
                // place for ever, and the instrument would answer nothing until
                // it was unplugged.
                tud_vendor_read_flush();
                reset_receiver();
                continue;
            }
            if (rx_header.length > MAX_REQUEST_PAYLOAD) {
                rx_discard = rx_header.length;
                respond(rx_header.opcode, rx_header.sequence, ST_BAD_LENGTH, NULL, 0, NULL, 0);
                reset_receiver();
                return;
            }
        }

        if (rx_payload_have < rx_header.length) {
            rx_payload_have += tud_vendor_read(rx_payload + rx_payload_have,
                                               rx_header.length - rx_payload_have);
            if (rx_payload_have < rx_header.length) return;
        }

        handle(&rx_header, rx_payload);
        reset_receiver();
        return;
    }
}

int main(void)
{
#if PILYZER_WIFI
    // The radio is a second way in, never the only one. It is brought up
    // first, before anything else claims a PIO, a DMA channel or a pin, and
    // before USB appears, since loading its firmware takes a moment the host
    // would otherwise spend waiting. Joining the network then goes on in
    // wifi_poll, a step at a time, and USB never waits for it.
    wifi_start(PILYZER_WIFI_SSID, PILYZER_WIFI_PASSWORD, PILYZER_HOSTNAME);
#endif
#ifdef PICO_DEFAULT_LED_PIN
    gpio_init(PICO_DEFAULT_LED_PIN);
    gpio_set_dir(PICO_DEFAULT_LED_PIN, GPIO_OUT);
#endif
    for (uint8_t channel = 0; channel < ANALOG_CHANNELS; channel++) {
        for (uint8_t pin = 0; pin < RANGE_PINS_PER_CHANNEL; pin++) {
            gpio_init(range_pin(channel) + pin);
            gpio_set_dir(range_pin(channel) + pin, GPIO_OUT);
        }
        set_input_range(channel, 0);
    }
    set_calibration_output(true, 1000);

    analog_init();
    logic_init();
    signals_init();

    tusb_init();

    while (true) {
#if PILYZER_WIFI
        wifi_poll();
#endif
        tud_task();
        analog_poll();
        logic_poll();
        pump_receive();
        pump_transmit();

        if (reboot_when_drained && !transmitting()) {
            sleep_ms(20);            // let the last packet leave before the link drops
            reset_usb_boot(0, 0);
        }
    }
}

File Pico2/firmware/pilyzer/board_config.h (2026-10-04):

// Pin map and memory budget for the PiLyzer Pico 2 instrument.
//
// Everything the rest of the firmware knows about the board is here. The
// numbers below are what the host is told through OP_CAPABILITIES, so the
// application never has to be recompiled when they change.
#pragma once

#ifndef PILYZER_BOARD_ID
// 0 = bare Pico 2, inputs straight on the converter pins.
// 1 = PiLyzer analogue front end rev A/B.
// 0 bare Pico 2, 1 PiLyzer AFE rev A, 3 PL2407AFE. 2 was a second in-house
// board and is retired rather than reused, so an old build that still says 2
// fails here instead of quietly reading through rev A's ranges.
#define PILYZER_BOARD_ID 0
#endif

#define PILYZER_FIRMWARE_VERSION 0x0113   // 1.19: builds for the original Pico (RP2040) as well

// What it calls itself, to the host and over USB.
#if PICO_RP2040
#define PILYZER_PRODUCT_NAME "PiLyzer Pico"
#else
#define PILYZER_PRODUCT_NAME "PiLyzer Pico 2"
#endif

// --- Pins ---------------------------------------------------------------
#if PILYZER_BOARD_ID == 3
#include "../../hardware/pl2407afe/board_config.h"
// Two pins a channel here, and they are 2-5, which is why this board was the
// first to want the generator somewhere other than 0.
#define RANGE_PINS_PER_CHANNEL 2
#define PIN_SIGNAL_BASE     16
#define PILYZER_HAS_SIGNALS 1
#else
// The PL2407AFE brings its own SG OUT pad on GPIO22, so every board uses that
// pin and nothing has to ask which board it is talking to.
#define PIN_CALIBRATION_OUT 22    // adjustable calibration square wave
// A sine and three noises, one per pin from here up. Every board puts them on
// the same four, so there is one answer to where they are rather than one an
// application has to look up; the range controls moved down to 4 to free them.
#define PIN_SIGNAL_BASE     16
#define PILYZER_HAS_SIGNALS 1
// Logic and the range controls sit where the PL2407AFE has them, so D0 is
// GPIO6 whichever board it is: one answer to where the logic inputs are.
#define PIN_LOGIC_BASE      6     // D0…D7 on GPIO6…GPIO13, consecutive for PIO
#define RANGE_PINS_PER_CHANNEL 1
#define PIN_RANGE_CH1       2     // switch position: 0 = ±25 V, 1 = ±5 V
#define PIN_RANGE_CH2       3
#define PIN_RANGE_CH3       4
#define PIN_LED             PICO_DEFAULT_LED_PIN
#define PIN_ADC_CH1         26    // ADC0
#define PIN_ADC_CH2         27    // ADC1
#define PIN_ADC_CH3         28    // ADC2

#define ANALOG_CHANNELS 3
#define LOGIC_CHANNELS  8
#endif

// --- Input ranges -------------------------------------------------------
// The straight line from a voltage at the input to a voltage at the converter,
// one entry per position of the range switch.
//
// These used to live in the host, selected by board id, which meant every new
// board needed a new release of both applications before it could be read
// correctly — the one place where the host used a compiled-in constant instead
// of the device's own answer. They belong here, with the board.
//
//   gain   converter volts per input volt, in millionths
//   offset converter volts with 0 V at the input, in microvolts
//
// A bare Pico 2 has nothing to switch, so it offers exactly one.
#if PILYZER_BOARD_ID == 3
// PL2407AFE descriptors are supplied by hardware/pl2407afe/board_config.h.
#elif PILYZER_BOARD_ID == 0
#define ANALOG_RANGES 1
#define PILYZER_INPUT_RANGES {                                                 \
    { .switch_position = 0, .gain_micro = 1000000, .offset_microvolts = 0,     \
      .name = "0 – 3.3 V" },                                                   \
}
#elif PILYZER_BOARD_ID == 2
#error "board id 2 is retired; a one-range rev A build reports its own ranges"
#else
// PiLyzer AFE rev A: both ranges sit on the same attenuator and the same
// mid-rail bias; the switch only changes the gain of the stage after it.
#define ANALOG_RANGES 2
#define PILYZER_INPUT_RANGES {                                                 \
    { .switch_position = 0, .gain_micro =  62645, .offset_microvolts = 1650515,\
      .name = "±25 V" },                                                       \
    { .switch_position = 1, .gain_micro = 297269, .offset_microvolts = 1652442,\
      .name = "±5 V" },                                                        \
}
#endif
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

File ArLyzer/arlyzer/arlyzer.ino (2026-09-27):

// ArLyzer: the PiLyzer wire protocol (Pico2/docs/protocol.md) on an Arduino
// Nano R4, UNO R4 Minima or UNO R4 WiFi, eight analogue inputs (seven on the
// WiFi): immediate readings for the meter, timed, triggered records for the
// oscilloscope and the spectrum, and a logic analyser on D2–D9.
//
// The transport is the board's USB CDC serial, not the vendor bulk interface
// the Pico uses. The stock Renesas core builds its own USB descriptors and
// compiles TinyUSB's vendor class out (CFG_TUD_VENDOR 0 in the variant's
// tusb_config.h), so a sketch cannot add one. The frames are byte-for-byte the
// same; only what carries them differs.
//
// On the WiFi the USB port is the ESP32-S3's, which passes the bytes on over a
// UART at whatever rate the host opened the port at; on the others the rate
// means nothing.
//
// This file is the board: the pins, the serial port and the meter's readings.
// The protocol is instrument.cpp, the record's logic record.cpp, and the timer
// and converter that feed it acquisition.cpp.

#include <Arduino.h>
#include "acquisition.h"
#include "instrument.h"

namespace {

constexpr uint8_t kChannels = acquisition::kChannels;
#if defined(ARDUINO_MINIMA)
// The UNO has only A0–A5 on its analogue header, but D4 and D5 are converter
// inputs as well (P103 = AN019, P102 = AN020).
constexpr uint32_t kBoardId = 5;
constexpr char kName[] = "ArLyzer R4 Minima";
const uint8_t kPins[kChannels] = {A0, A1, A2, A3, A4, A5, 4, 5};
#elif defined(ARDUINO_UNOWIFIR4)
// On the WiFi the one converter input off the analogue header that is free is
// D10 (P103 = AN019). D13 (P102 = AN020) would be the next, but it carries the
// board's LED, and there is no RAM for an eighth input anyway (record.h).
constexpr uint32_t kBoardId = 6;
constexpr char kName[] = "ArLyzer R4 WiFi";
const uint8_t kPins[kChannels] = {A0, A1, A2, A3, A4, A5, 10};
#else
constexpr uint32_t kBoardId = 4;
constexpr char kName[] = "ArLyzer Nano R4";
const uint8_t kPins[kChannels] = {A0, A1, A2, A3, A4, A5, A6, A7};
#endif

// Logic D0–D7 are the board's D2–D9 on every R4: D0 and D1 are the serial
// port's on the UNOs, and D10–D13 SPI's.
const uint8_t kLogicPins[acquisition::kLogicChannels] = {2, 3, 4, 5, 6, 7, 8, 9};

// analogRead(4) is A4, not D4: a number below A0 is taken as an analogue
// index. The port-and-pin form reads the pin itself, whichever header it is on.
int readPin(uint8_t pin) { return analogRead(digitalPinToBspPin(pin)); }

void writeSerial(const uint8_t *data, size_t length) { Serial.write(data, length); }

// A serial stream and the requests arriving on it.
struct Link {
  arduino::HardwareSerial &serial;
  instrument::Port port;
  uint32_t lastByteMs;
};

void serve(Link &link) {
  while (link.serial.available()) {
    const int b = link.serial.read();
    if (b < 0) break;
    link.port.receive(static_cast<uint8_t>(b));
    link.lastByteMs = millis();
  }
  // A host sends a request all at once, so one quiet this long is not coming.
  if (millis() - link.lastByteMs > 50) link.port.flush();
}

Link usb{Serial, instrument::Port(writeSerial), 0};

#if defined(ARDUINO_UNOWIFIR4)
// The USB side's receive interrupts, a step above the other UART interrupts
// (12) and still well below the tick (4). With the bridge asking after the
// network once a second, a request from USB lost about one byte in three
// hundred to an overrun on SCI9 while SCI1 was receiving: SCI1's receive
// interrupt holds SCI9's off longer than the 43 µs a byte takes at 230400.
// Raising SCI1's as well brought the overruns back, so it stays where it is.
void raiseUsbReceive() {
  for (uint32_t irq = 0; irq < BSP_ICU_VECTOR_MAX_ENTRIES; irq++) {
    const uint32_t event = R_ICU->IELSR[irq] & 0x1FF;
    if (event == ELC_EVENT_SCI9_RXI || event == ELC_EVENT_SCI9_ERI) NVIC_SetPriority(static_cast<IRQn_Type>(irq), 11);
  }
}

// The WiFi's second UART, to the ESP32-S3, carries what its radio receives
// when the ESP32 runs ArLyzer's bridge (ArLyzer/bridge) rather than the stock
// one, and the bridge's own questions about the network it joins
// (network.h); with the stock one nothing arrives on it.
void writeRadio(const uint8_t *data, size_t length) { Serial2.write(data, length); }
Link radio{Serial2, instrument::Port(writeRadio, true), 0};
#endif

void sampleAll(uint16_t averages, uint16_t *readings) {
  if (averages == 0) averages = 1;
  if (averages > 4096) averages = 4096;
  uint32_t totals[kChannels] = {};
  for (uint16_t i = 0; i < averages; i++) {
    for (uint8_t c = 0; c < kChannels; c++) {
      (void)readPin(kPins[c]);  // the first conversion after the mux moves is not trustworthy
      totals[c] += readPin(kPins[c]);
    }
  }
  // Left-align from 14 bits into 16, as the protocol asks.
  for (uint8_t c = 0; c < kChannels; c++)
    readings[c] = static_cast<uint16_t>(static_cast<uint64_t>(totals[c]) * 4u / averages);
}

void setLED(bool on) { digitalWrite(LED_BUILTIN, on ? HIGH : LOW); }

}  // namespace

void setup() {
  pinMode(LED_BUILTIN, OUTPUT);
  analogReadResolution(14);
  acquisition::begin(kPins, kLogicPins);
  instrument::begin({kBoardId, kName, sampleAll, setLED});
  // The WiFi's UART takes an interrupt a byte, and with the tick at its
  // shortest there is little time for one: at 460800 and above, requests lost
  // bytes while a record was being taken (2026-09-26). Raising the UART above
  // the tick kept the bytes but made the ticks late instead. 230400 lost none.
  // A native CDC port ignores the rate; 1200 is the one that resets into the
  // bootloader on every board.
  Serial.begin(230400);
#if defined(ARDUINO_UNOWIFIR4)
  Serial2.begin(230400);
  raiseUsbReceive();
#endif
}

void loop() {
  serve(usb);
#if defined(ARDUINO_UNOWIFIR4)
  serve(radio);
#endif
  acquisition::poll();
}

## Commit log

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2026-09-07 Replace DPScope implementation with PiLyzer instrument stack
    [bom.csv]
2026-09-07 Fix capture boundaries, live settings, calibration and spectrum history
    [analog.c, analog_test.c, board_config.h]
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2026-09-07 Pace the converter at 97 cycles so the reported interval is the real one
    The pacing register holds the interval minus one and the converter only
    obeys it when that register is 96 or more. Asking for the documented
    96-cycle conversion wrote 95, below the threshold, so the converter
    abandoned pacing and free-ran at about twice the rate while the plan
    still reported the interval that was asked for. Measured on hardware: a
    1 kHz square read back as 2 kHz at every channel count's fastest sweep,
    and correctly at every slower one.
    The aggregate ceiling drops from 500 to 495 kSa/s, which is the price of
    the number being true. A firmware test now asserts the register stays in
    the honoured range and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
    [analog.c, analog_test.c, board_config.h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]
2026-09-07 Replace the passive RC pair with a Sallen-Key and drop the BNCs
    A third channel divides the converter three ways instead of two, so
    Nyquist fell from 124 to 82 kHz and the old passband reached past it:
    between 82 kHz and roughly 250 kHz a signal was neither rejected by the
    filter nor resolved by the converter, and folded back looking real.
    Each channel now ends in a unity-gain Sallen-Key on U4 — R 2.67k, C1
    2.2n, C2 1n to VMID — giving fc 40.2 kHz and Q 0.742, so 12.5 dB down at
    three-channel Nyquist instead of nearly nothing. The shunt returns to
    VMID rather than ground to keep the mid-rail bias ratiometric. R is a
    value the board already used and the amplifier is a second TLV9064, so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
    [bom.csv, channel-1.kicad_sch, channel-2.kicad_sch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]
2026-09-07 Fix the vertical scale, the centre line and everything they broke
    Four display faults, each found by using the instrument:
    The volts-a-division ladder stopped at span / divisions, which assumed
    every signal straddles zero. A 0–3.3 V rail had no setting that showed
    it whole. The ladder now reaches a step that fits the span in two
    divisions, so probe 1:1 offers 2 V.
    Zero volts was pinned to the centre line even on a front end that cannot
    go below zero, wasting half the screen. The centre is now the middle of
    what the channel can measure — snapped to exactly zero for a range that
    straddles it, so a bipolar range is unchanged — and a stale trigger
    level is moved somewhere the signal reac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
2026-09-08 Name WinUSB so the browser application works on Windows
    A vendor-specific interface is what makes this driverless on macOS and Linux —
    no kernel driver matches class 0xFF, so an application claims the interface
    itself. Windows binds by name instead, and with no name it binds nothing: the
    interface is visible and nothing can open it, Chrome included. That left the
    point of the browser port unmet on the platform it was written for.
    So the device names one for itself. bcdUSB becomes 2.1, which is what makes
    Windows ask for the BOS descriptor at all, and the BOS carries a Microsoft
    OS 2.0 descriptor set declaring the compatible id WINUSB with this project's own
    DeviceInterfaceGUIDs, plus a We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
    [board_config.h]
2026-09-08 Give X/Y a square grid and put the front panel back where it was left
    X/Y drew one voltage against another on the 10 × 8 sweep grid, so a division was
    99.9 pixels across and 51.4 down: every figure came out stretched to nearly two
    to one, and a circle was an ellipse. It gets a square grid of its own now, and
    the vertical axis is labelled from the channel it actually plots — the second
    one — rather than always from the first.
    A trigger level left behind by a range change used to clamp to the rail, where
    no signal ever reaches it. In Normal mode that is an instrument that waits for
    ever and looks broken, so the level is moved back inside the range as the native
    application already did. H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
2026-09-08 Hold both implementations of the wire format to one fixture
    The protocol is written twice, once in Swift and once in JavaScript, and the
    two had already drifted: the native side capped hysteresis at 4095 codes and
    truncated the sample period to femtoseconds where the browser rounded. Neither
    mattered yet, which is exactly the problem — nothing would have said so.
    tests/fixtures/wire-golden.json holds encodings written from docs/protocol.md
    rather than recorded from either implementation, and both sides are checked
    against it. The request header and the two configuration structures move out of
    the transport and the planners so there is something to check. Verified by
    reversing two fields o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
2026-09-09 Let the board describe its own front end
    The gain and offset of every input range were compiled into both applications
    and selected by board id — the one place either of them used a constant about a
    particular board instead of the device's own answer, which is the opposite of
    what docs/protocol.md says a host should do. With one board it cost nothing.
    With PiLyzer Lite and PiLyzer Pro it would have meant a release of the macOS
    application and the web application before either could read a new board
    correctly.
    So the board says. Opcode 0x07 returns one 32-byte InputRange per switch
    position — name, switch position, gain in millionths of a volt per volt, offset
    in microvolts — and capab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
    [board_config.h, main.c, pilyzer_protocol.h]
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2026-09-09 Say why the drawer full of DIP op amps will not do
    There is no through-hole TLV9064, so the question of substituting one comes up
    immediately, and the answer is not obvious from the schematic: LM358, TL072 and
    the rest fail on the supply rail before bandwidth is even discussed, and the two
    modern DIP parts that pass rail-to-rail on 3.3 V mostly fail on bandwidth.
    The reasoning is worth keeping rather than rediscovering. The filter's Q and the
    clamp's leakage are measurements of the amplifier as much as of the circuit
    around it — a bipolar input's 45 nA buries the 1 nA being looked for under
    forty-five of its own, and a 1 MHz part sits 25 times above the filter's corner
    where the specified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
    [bom.csv]
2026-09-09 Say how to change range by hand, and where that bites
    Standing in for the analogue switch with a wire is right, but the previous note
    said "lift it for ±25 V" and left two things out.
    Pull R8 out instead of lifting one end. Its other end is on the amplifier's
    inverting input, and a free wire on a high-impedance summing node is an aerial —
    a breadboard's much more so than a PCB trace. An empty pair of holes is what
    "connected to nothing" is meant to be.
    And the application still sends setRange, which with no switch fitted drives
    nothing while still applying that range's gain and offset to every reading.
    Select ±5 V with R8 out and every number is wrong by the ratio of the two
    ranges, wi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
    [bom.csv]
2026-09-09 Define PiLyzer Lite as one range, and say the switch is an SPST
    Lite offers ±5 V and nothing else, so `R8` is wired to VMID rather than taken
    there by a switch, and both TS5A23159 packages leave the board along with the
    GPIO16/17 that drove them. `PILYZER_BOARD_ID 2` builds it; the software-range
    capability now follows the range count rather than the board id, since a board
    with one range has nothing to switch whatever its number is.
    Everything in front of the gain stage stays, because that is where the input
    protection lives rather than where the range is chosen. The fixed 1 MΩ
    attenuator still means ±25 V clips without the clamp conducting at all and
    ±100 V is still the continuous rat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
    [board_config.h, main.c]
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2026-09-09 Widen the compensation window, and give Lite a fixed capacitor to aim at
    The divider is flat when C_top = C_node / 14.96, and C_node is C4 plus whatever
    the layout adds. With C1 at 6.8 pF and TC1 at 0.5–3 pF the adjustable window was
    7.3 to 9.8 pF, which is a node stray of 27 to 65 pF — high for a board this
    small. Below 27 pF the trimmer bottoms out over-compensated with nowhere left to
    go, and the board cannot be trimmed flat at all.
    C1 is 5.6 pF now, which puts the window at 6.1 to 8.6 pF and a stray of 9 to
    47 pF, straddling what a node with an amplifier input, a clamp, a trimmer body
    and a test point on it plausibly comes to.
    Measurement would not have caught this. A breadboard's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
    [bom.csv, channel-1.kicad_sch, channel-2.kicad_sch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]
2026-09-09 Capture PiLyzer Lite: two channels, one fixed ±15 V range
    Derived from rev A rather than drawn again, because Lite is that circuit with
    things taken out: the third channel, both analogue switches, and the GPIOs that
    drove them. What is left is 70 parts against 93.
    Three values carry the whole electrical difference. R8 is 15 kΩ wired to VMID
    instead of 2.67 kΩ taken there by a switch, which fixes the stage at ×1.667 and
    the range at −15.81 to +15.80 V. C4 is 220 pF instead of 82, so the layout's
    stray is a smaller fraction of the node and a fixed capacitor can hold the
    compensation to a few per cent — which is what lets production Lite drop the
    trimmer a teaching board should not hav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
    [bom.csv, channel-1.kicad_sch, channel-2.kicad_sch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]
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2026-09-13 Give the instrument the sine and the noises, on its own pins
    GPIO0–3 were free on every board that puts its logic at 8 and its ranges at 16,
    so the instrument now carries the generator it was going to need a second Pico
    for: 440 Hz on GPIO0 and white, pink and brown noise on GPIO1, 2 and 3, from
    firmware 1.9 and opcode 8.
    It is the same file the spare-board program runs — that program now compiles
    the instrument's copy — so there is one generator and one set of tests. The
    board says whether it has one, capability bit 5: a PL2407AFE switches its
    ranges on GPIO2–5, so board id 3 answers that it has none rather than fighting
    over the pins.
    Switched off until the panel asks, and the pa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
    [board_config.h, main.c, pilyzer_protocol.h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]
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2026-09-14 Move the rev A range and calibration nets to where the firmware looks
    Firmware 1.11 took the range controls down to GPIO4/5/6 so the generator
    could have GPIO16-19 on every board, and 1.12 put the square wave on
    GPIO22. The schematic still drew the old map, which check_kicad.py has
    been reporting ever since; this is the redraw it was asking for.
    RANGE_CH1/2/3 move from J7.20/19/17 to J6.6/7/9, and CAL_GPIO20 on J7.15
    becomes CAL_GPIO22 on J7.12. Each was a 7.62 mm stub to a global label,
    so the nets themselves are unchanged — only which pad they land on. The
    no-connect flags swap with them: off the three J6 pads that are now
    driven and the J7 pad that now carries the square wave, onto the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
    [pilyzer-afe.kicad_sch]
2026-09-14 Move the Lite's square wave to GPIO22 as well
    The same change as rev A's, minus the range nets: the Lite has no
    analogue switch, so only CAL_GPIO20 on J7.15 had to become CAL_GPIO22 on
    J7.12, with the no-connect flag swapping to the pad it left. The sheet
    note now says the generator has GPIO16-19 rather than that they are
    unused.
    check_lite.py passes its 25 groups and ERC stays at 0 and 0. Only the
    root preview is re-exported; the two channel sheets were unchanged, so
    they keep the files they had rather than a new timestamp. These previews
    are exported without a background, unlike rev A's — each project keeps
    the way its own were made.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
    [pilyzer-lite.kicad_sch]
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2026-09-14 Turn the labels that were pointing into their own symbols
    A global label is drawn on one side of its anchor, and twenty-four of
    them across the two projects were set to the side the connection is on,
    so the flag was laid over the thing it names. U4D was the clearest: both
    its input labels sat across the triangle. The same pattern hid C21's
    plates and R44's body on every channel sheet.
    The rule is only that the label extends away from what it connects to,
    so the fix is the justification alone — no anchor, wire or net moves.
    check_kicad.py still passes its 54 net groups and check_lite.py its 25,
    and both ERC reports stay at 0 and 0.
    Found by walking every label, resolving what its anchor t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
    [channel-1.kicad_sch, channel-2.kicad_sch, channel-3.kicad_sch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]
2026-09-14 Drop the two GND labels out of the amplifiers they sat inside
    The sweep that turned the sideways labels round only looked at the ones
    lying left and right, and these four are rotated: +3V3 above each of U4C
    and U4E, GND below. The two GND labels were drawn upward, so each landed
    across its own amplifier — over U4C's triangle and its decoupling
    capacitor, and over U4E's pin 11 and stub.
    Only the GND ones. A rotated label's justification means the same
    direction whichever way round it is turned, so above and below need
    opposite settings, and the +3V3 pair was already pointing away. Turning
    all four the same way fixed GND and broke +3V3, which the render showed
    before it went anywhere near a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
    [pilyzer-afe.kicad_sch, pilyzer-lite.kicad_sch]
2026-09-14 Move the decoupling capacitors off the parts they were drawn over
    The smear at U4C was two symbols at one coordinate: C24 sat exactly on
    the amplifier, so its plates crossed the triangle and "C24 / 100n X7R"
    printed on top of "U4 / TLV9064IDR". Nothing was wrong with the wiring —
    the same text twice in the same place is just unreadable.
    C24 moves 25.4 mm down, into the empty band under U4C, with its +3V3 and
    GND labels and its text set out the way C14's is.
    Looking for the same thing elsewhere turned up one more: on rev A, C13
    and C24 are 2.54 mm apart, which is narrower than a capacitor and its
    labels, so those two were drawn through each other. C24 moves 10.16 mm
    right and the pair now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
    [pilyzer-afe.kicad_sch, pilyzer-lite.kicad_sch]
2026-09-14 Join U4A to R44 with a wire and let one label name the net
    The two CHn_FILT labels between the amplifier's output and the resistor
    were what joined those pins, which is why neither could go while each
    had to point away from its own part and they met in the middle. A wire
    does the joining now, so one label is enough and there is room for it.
    The label at R44's pin stays and the one at U4A's output goes. The net
    still has its name from three places — that pin, U4A's inverting input,
    and C21 — so nothing about the connection changes: check_kicad.py passes
    its 54 net groups and check_lite.py its 25, both unchanged, and ERC is
    0 and 0 on both projects.
    Five channel sheets, the same edit on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
    [channel-1.kicad_sch, channel-2.kicad_sch, channel-3.kicad_sch]
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2026-09-14 Call the schematic rev A, since no board has been made from it
    The title blocks said B on all four sheets, which reads as a second
    revision of something already fabricated. Nothing has been fabricated:
    the sheets are the first board, still being drawn. So they say A, and
    their date moves from 2026-09-08 to today, which is when they were last
    touched.
    The prose follows. The third channel is not a rev B addition but simply
    part of the board, and the pin map is not a rev B pin map but the pin
    map. The one place that still says rev B is the note about 5 V logic
    needing a level shifter, which is the future-revision sense and now
    reads correctly rather than describing the sheet in hand.
    Co-Autho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
    [channel-1.kicad_sch, channel-2.kicad_sch, channel-3.kicad_sch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]
2026-09-14 Leave the clamp off the breadboard build
    D1 and its SOT-23 adapter come out of the bill of materials, and the two
    diodes come out of the simulation with them. The transfer is unchanged to
    four figures — 1.652 / 3.139 / 0.1662 V at the converter for 0 / +5 / −5 V
    in, the same numbers as with the clamp in place, because it never conducts
    inside the range.
    What is lost is said rather than left to be discovered. The 1 MΩ input is
    what does the protecting on either board — it is what turns 100 V at the
    probe into 96 µA — but the last few volts now land on the op amp's own
    input diodes, which are not specified for it and leak more than a BAV199,
    so the note says to keep the input inside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
    [bom.csv]
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2026-09-15 Give the firmware an HTTP head and a way to answer without USB
    The half of a web server worth testing is the parsing, so it is a file
    of its own with no lwIP under it and a host test over it, the same
    arrangement the analogue and logic modules already use. The test walks
    every split point of a request to prove that a head arriving in pieces
    reads as early rather than as malformed, which is the mistake a server
    gets to make once.
    pilyzer_execute() is the seam the socket will use. The command layer
    never knew what was carrying it — handle() fills the same two buffers
    whoever asks — so a transport that frames its own messages can read them
    instead of pumping them at an endpoint. It refuses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
    [main.c]
2026-09-15 Serve the front panel from a Pico 2 W, so a phone can reach it
    The last piece: a build that brings the radio up, joins a network, and
    hands out the application over HTTP with POST /rpc beside it. Open
    http://pilyzer.local and it is the same front panel, with no address to
    type and no network to switch to — Safari resolves .local natively, which
    is what makes station mode the right first answer. An access point would
    have meant writing a DHCP server as well, and taking the phone off its
    own network to use one.
    Station mode also keeps the credentials out of the repository: SSID and
    password are cache variables, and without -DPILYZER_WIFI=ON the build is
    untouched — pico2, no radio, 41 kB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
    [main.c, wifi.c]
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2026-09-18 Make the Pico 2 W build work on a real Pico 2 W
    First time on hardware, and it never came up. What the bench showed:
    - Joining blocked for up to 30 s with USB started and tud_task not
    running, so the Mac gave up on the device. Joining is now a state the
    main loop steps through; the radio starts before USB, and a failed join
    retries every 40 s.
    - A GPIO request to the radio (the LED) sent while a join was in progress
    never got an answer, and the loop stopped dead, USB with it. The LED
    now only lights once the page is being served.
    - lwIP's timer pool had no room for the mDNS responder's timers; an empty
    pool is a panic. Eight more.
    - The server took two connections; a browser ope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
    [main.c, wifi.c]
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2026-09-21 Flush the receive pipe when a request puts the stream out of step
    The receiver is a byte stream, so a request whose length field disagrees
    with the bytes that followed it leaves the difference in the pipe. Every
    header read after that starts in the wrong place, the magic never
    matches, and reset_receiver() only cleared the counters — it read from
    the same wrong place for ever. One malformed request from any host wedged
    the instrument until it was unplugged, which is what happened on the
    bench today.
    The comment already claimed it threw away everything queued. Now it does.
    [board_config.h, main.c]
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2026-09-21 Measure the +-1.5 V gain with the +-6 V range as the ruler
    Five volts overruns that range, and the only cell near it reads 1.30 on a
    meter that stops there — a tenth of a percent of the reading, which would
    be four tenths of a percent of gain. The +-6 V range is already calibrated
    and reads the same cell as 1.3078 V, so it carries only the error of the
    five volt pass and halves the uncertainty.
    That leans on the circuit being linear. It is: the +-30 V gain comes out
    the same at 5.01 V and at 1.3 V to within 0.03 %.
    The answer is 0.880496 against a calculated 0.880411, a hundredth of a
    percent apart — far inside the measurement. So the nominal figure was
    right for this range, and that u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
    [board_config.h]
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2026-09-26 Shorten ArLyzer's tick to 10 µs and 1.4 µs an input
    The floor was 10 µs a channel, so eight inputs sampled at 12.5 kSa/s. It is
    now a fixed part and a part for each input, as measured: one input at
    88 kSa/s, four at 64, eight at 47. The interrupt starts the next scan before
    recording the last one, so the converter and the record overlap.
    Lost ticks are now caught by how far the interrupt has fallen behind in
    total, not by one long gap: the old check let the interrupt slip a little
    each tick, and a 1 kHz square read as 1152 Hz without an overrun.
    Firmware 0.4.
    [acquisition.cpp, record.h]
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2026-09-26 Run ArLyzer on an UNO R4 WiFi, with seven inputs over its UART bridge
    The WiFi's USB port is an ESP32-S3 that passes the bytes on over a UART at
    the rate the host opens the port at. Its UART takes an interrupt a byte, and
    with the tick at its shortest there is little time for one: at 460800 and
    above, requests lost bytes while a record was being taken, and raising the
    UART above the tick only made the ticks late instead. At 230400 ten records
    of one input and ten of seven all completed at the shortest tick. The sketch
    listens at 230400 on every board; a native CDC port ignores the rate.
    It has seven inputs, A0–A5 and D10 (AN019): its core links in every UART it
    has, which leaves no room f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
    [acquisition.cpp, arlyzer.ino, record.h]
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2026-09-26 Say how far ArLyzer's time axis can be off
    The timer runs from the RA4M1's untrimmed on-chip oscillator, good to
    ±1 %, with no crystal on any of these boards to hold it to. The first UNO R4
    WiFi's runs 0.19 % slow, so a 1 kHz square reads 1001.9 Hz on it; that is
    left as it is rather than corrected for one board.
    [acquisition.cpp]
2026-09-26 Let ArLyzer answer on more than one serial port
    Each port now keeps its own half-received frame and sends its replies back
    where the request came from. The UNO R4 WiFi answers on its USB port and on
    its second UART to the ESP32-S3, which is where ArLyzer's own bridge
    firmware will pass on what arrives over the radio; with Arduino's firmware
    nothing arrives there and USB works as before (checked: ten records each of
    one and seven inputs at the shortest tick).
    [arlyzer.ino]
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2026-09-27 Let a host tell a Pico 2 W which network to join
    The Wi-Fi build had the network's name and password compiled in, so the
    UF2 carried them and could not be released. Now a host sets them over USB
    with setNetwork (0x09): network, password and the name it answers to,
    kept in flash and read back, password aside, with networkStatus (0x0A).
    Capability bit 6 says the board takes them. -DPILYZER_WIFI_SSID is now
    optional: a network baked in is only where a board starts, and one set
    over USB takes its place.
    - The network lives in the last flash sector but one. The last one looked
    natural, but every RP2350 UF2 carries a block at 0x10FFFF00 (the SDK's
    erratum E10 workaround) which on a 4 MB chip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
    [board_config.h, main.c, pilyzer_protocol.h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]
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2026-10-04 Drop every mention of CH1's +-6 V switch not closing
    The PL2407AFE's README, its board_config.h, and episode 3's script and
    shot lists no longer describe it: the section, the scene at 5:45 with
    its card and shots (later sections move up two minutes), and the notes
    beside the measurements, where CH1's +-6 V cell is now a dash.
    [board_config.h]
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

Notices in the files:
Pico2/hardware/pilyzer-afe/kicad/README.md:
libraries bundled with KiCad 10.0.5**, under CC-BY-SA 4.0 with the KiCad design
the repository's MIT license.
